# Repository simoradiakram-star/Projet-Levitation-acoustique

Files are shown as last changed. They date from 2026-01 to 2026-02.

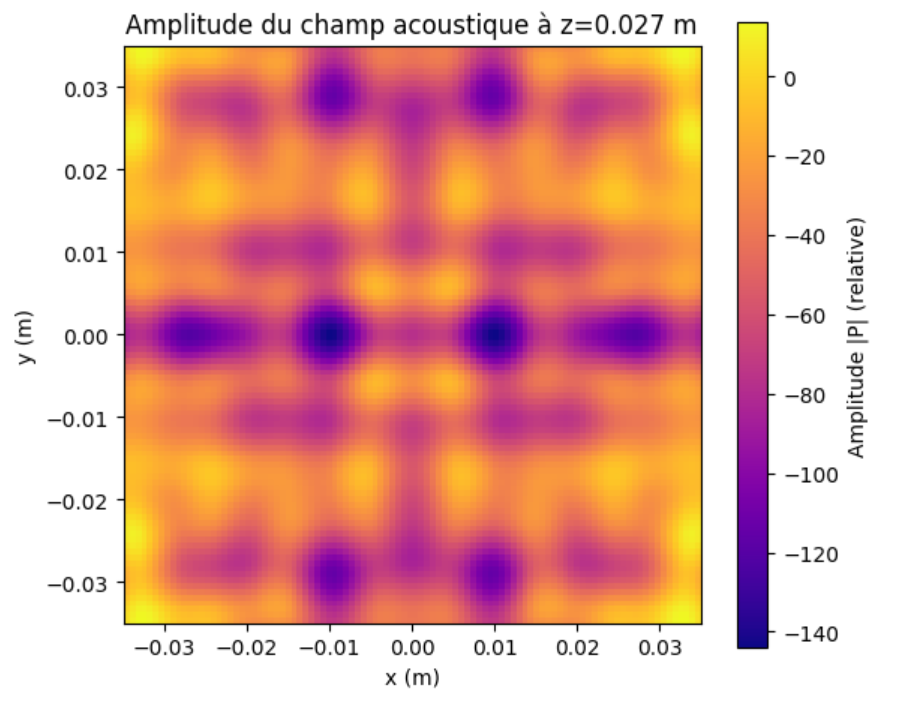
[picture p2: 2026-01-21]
Projet G1-G2/Lévitateur à deux plaques/Physique Théorique/Photos/optimizer 1 plaque (2).png

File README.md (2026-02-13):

# Système de Lévitation Acoustique

**Projet (G1 / G2) — Centrale Lille**

Développement d'un dispositif expérimental de manipulation sans contact par pinces acoustiques.

Photo_lévitation_1bille_bis

---

### À propos

Ce projet vise à concevoir et réaliser un système de lévitation acoustique à **faible coût**. L'objectif principal est de permettre la manipulation sans contact d'objets millimétriques (tels que des billes de polystyrène ou de petits insectes) dans l'air.

Ce travail s'inscrit dans la continuité des recherches du groupe **AIMAN-FILMS (IEMN)**, qui développe des technologies de pinces acoustiques pour des applications biomédicales (déplacement de cellules en milieu stérile). Notre prototype adapte ces concepts pour une application macroscopique dans l'air.

---

### 1. Objectifs

* **Conception :** Réaliser un prototype fonctionnel intégrant l'électronique et la structure mécanique.
* **Manipulation :** Réussir la lévitation stable d'objets millimétriques.
* **Démonstration :** Prouver la faisabilité d'applications potentielles (ex: manipulation d'échantillons fragiles).

### 2. Technologies et Compétences

Ce projet mobilise des compétences pluridisciplinaires :

* **Hardware / Électronique :** Soudure de cartes électroniques, pilotage de transducteurs.
* **Système embarqué :** Programmation sur Arduino.
* **Mécanique :** Modélisation et Impression 3D de la structure (support des transducteurs).
* **Physique :** Principes des ondes stationnaires et de la pression de radiation acoustique.

### 3. Partenaires et Encadrement

Ce projet est réalisé en partenariat avec le groupe **AIMAN-FILMS** de l'**IEMN** (Institut d'Électronique, de Microélectronique et de Nanotechnologie).

### 4. Contacts académiques

* **Olivier Bou Matar-Lacaze** (Centrale Lille / IEMN)
* **Abdelkrim Talbi** (Centrale Lille / IEMN)

---

Voici l'architecture globale du GitHub :

```
└── Projet-Levitation-acoustique
    ├── Lévitateur à deux plaques
    │   ├── Electronique
    │   │   ├── Circuits
    │   │   └── Composants
    │   ├── Informatique
    │   │   └── Communication 2 Arduino
    │   ├── Notices
    │   ├── Physique Théorique
    │   │   ├── Calcul des phases
    │   │   └── Photos
    │   └── Résultats  <-- (Vidéos de lévitation, rapports de tests)
    │
    ├── Lévitateur à une plaque
    │   ├── Electronique
    │   │   ├── Circuits
    │   │   └── Composants
    │   ├── Informatique
    │   │   ├── Code Arduino Mega
    │   │   │   ├── DriverMega
    │   │   │   └── NewDriverMega
    │   │   └── Codes Arduino Mega
    │   │       └── DriverMega
    │   ├── Notices
    │   ├── Physique théorique
    │   │   ├── Calcul des phases
    │   │   └── Photos
    │   └── Résultats  <-- (Vidéos, mesures de précision)
    │
    └── TinyLev
        └── Résultats  <-- (Démonstration du prototype compact)
```

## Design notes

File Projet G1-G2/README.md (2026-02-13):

# 📁 Nos Prototypes

Ce répertoire contient 3 dossiers permettant d'identifier clairement les 3 prototypes réalisés durant notre projet :

## 1. TinyLev (Prototype de Validation)

Le **TinyLev** est un lévitateur à ondes stationnaires.

* **Objectif** : Valider les principes fondamentaux de la lévitation acoustique et tester la chaîne d'amplification.
* **Caractéristique** : Utilise deux supports imprimés en 3D suivant une courbe prédéfinie pour focaliser les ultrasons au centre.

TinyLevenfonctionnement (1)

## 2. Lévitateur à Simple Plaque

Ce prototype marque le passage au contrôle dynamique via une matrice unique de **8x8 transducteurs**.

* **Capacités** : Permet de tester les algorithmes de calcul de phase (**Optimizer** et **Vortex**).
* **Limites** : Bien qu'il valide la création de pièges acoustiques, la force de lévitation reste limitée par l'absence d'une source d'opposition, rendant le piégeage d'objets lourds complexe.



## 3. Lévitateur à Double Plaques

Version la plus aboutie du projet, elle intègre deux matrices de transducteurs placées face à face.

* **Fonctionnement** : Génère des ondes stationnaires contrôlées par la synchronisation des deux plaques.
* **Avantages** :
* Augmentation considérable de la **force de piégeage**.
* **Stabilité supérieure** permettant la manipulation de liquides ou de plusieurs particules simultanément.

Photo_lévitation_1bille_bis

---

*Pour comprendre le déroulement de notre projet plus en détail et avoir une vue d'ensemble, vous pouvez vous référer à la documentation technique située à la racine de ce dossier.*

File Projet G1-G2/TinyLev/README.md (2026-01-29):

# Prototype 1 : TinyLev

Le **TinyLev** constitue la première étape concrète du projet. Il s'agit d'un lévitateur acoustique à ondes stationnaires dont la géométrie est fixe, permettant de valider les concepts physiques fondamentaux avant de passer à des systèmes dynamiques.

## Raison d'être

L'objectif principal de ce prototype était de :

* Confirmer la faisabilité de la lévitation d'objets millimétriques (billes de polystyrène) ;
* Se familiariser avec la manipulation des transducteurs ultrasonores à 40 kHz.

## Fonctionnalités

* **Focalisation géométrique** : La courbure de la structure imprimée en 3D assure la convergence des faisceaux ultrasonores vers un point focal central ;
* **Ondes stationnaires** : Création de nœuds de pression stables par interférence d'ondes permettant de piéger des particules à des positions fixes ;
* **Simplicité matérielle** : Pilotage via un Arduino Nano et une alimentation directe, sans besoin de calcul de phase complexe en temps réel.

## Limites

* **Position fixe** : Les pièges acoustiques sont statiques : il est impossible de déplacer la particule une fois lévitée ;
* **Absence de contrôle logiciel** : Le déphasage est induit par la position physique des transducteurs et non par le code.

## Évolution : Vers le Prototype 2 (Monoplaque)

Le succès du TinyLev a démontré que notre électronique de puissance était fiable. Cependant, pour répondre aux objectifs de manipulation dynamique, nous avons dû abandonner la géométrie fixe au profit d'une **matrice plane (8x8)** dont nous contrôlons chacun des transducteurs individuellement.

Le passage au prototype suivant permet d'introduire le **contrôle logiciel des phases**, offrant la flexibilité nécessaire pour déplacer les pièges acoustiques et manipuler les particules dans l'espace.

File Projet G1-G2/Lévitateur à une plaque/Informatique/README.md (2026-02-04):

# Pilotage Informatique - Lévitateur à une plaque

Ce dossier contient l'ensemble des ressources logicielles nécessaires au fonctionnement du prototype de lévitation acoustique à une plaque. 

## Structure du dossier

* **`Codes arduino mega/`** : Contient les scripts `.ino` pour l'Arduino Mega ainsi que les documentations d'explication de ces codes ;
* 
**`Passage_Phases_python_pin.ipynb`** : Notebook Python permettant de convertir les phases théoriques calculées en données binaires (octets) compréhensibles par l'Arduino.

---

## 🛠️ Instructions d'utilisation

### 1. Calcul des phases et conversion

Avant de téléverser le code sur l'Arduino, vous devez définir la position du piège acoustique :

1. Utilisez les scripts de calcul (Optimizer ou Vortex dans la partie physique théorique de la palque seule) pour obtenir les **phases réelles** (en radians) pour les 64 transducteurs ;
2. Ouvrez le notebook **`Passage_Phases_python_pin.ipynb`** ;
3. Renseignez vos phases réelles dans le tableau `Phi_64` ;
4. Exécutez le script pour générer le **bit buffer** (liste d'octets) ;
5. Copiez ces octets pour l'étape suivante.

### 2. Configuration de l'Arduino Mega

Le code de pilotage est une version optimisée du `DriverMega` original, nommée `NewDriverMega`.

1. Ouvrez le sketch dans le dossier `Codes arduino mega`.
2. Remplacez les octets de la variable `patterns` (ligne 24 environ) par ceux générés par le notebook.

3. **Note sur les motifs (patterns)** : Le code est configuré pour 2 motifs.
* Pour un piège statique : copiez deux fois le même set de phases.
* Pour un déplacement : renseignez deux sets de phases proches l'un de l'autre.

4. Sélectionnez la carte **Arduino Mega** dans l'IDE et téléversez le programme.

---

## ⚠️ Précautions

* 
**Alimentation** : Ne jamais dépasser **29V** sur la carte d'amplification.

* 
**Connectique** : Vérifiez la continuité des câbles en nappe, car des fils trop fins peuvent causer des pertes de signal.

* 
**Synchronisation** : Si le signal n'est pas stable à l'oscilloscope, ajustez ou supprimez le nombre de `nop` dans la fonction `WAIT()`.

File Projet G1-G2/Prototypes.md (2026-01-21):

Nos Prototypes
Lévitateur à Simple Plaque (Phase 2) Ce prototype initial utilise une matrice unique de 8x8 transducteurs. Il a permis de valider les algorithmes de calcul de phase (Optimizer et Vortex) pour créer des pièges acoustiques , bien que la force de lévitation reste limitée dans cette configuration.

Lévitateur à Double Plaque (Phase 3) Cette version évoluée intègre deux matrices de transducteurs placées face à face. Grâce à la génération d'ondes stationnaires, ce système augmente considérablement la force de piégeage , offrant une stabilité supérieure nécessaire pour faire léviter des liquides ou manipuler plusieurs particules simultanément.

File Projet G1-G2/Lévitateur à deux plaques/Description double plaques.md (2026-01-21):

# Prototype 2 : Lévitateur à Double Plaque

Ce prototype constitue la phase 3 du projet. Il utilise deux matrices en vis-à-vis pour créer des ondes stationnaires et augmenter la force de lévitation.

## Organisation des dossiers

### 📁 Electronique
Ce dossier détaille l'adaptation matérielle pour deux plaques :
* **Schémas** 
* **Câblage** 

### 📁 Informatique
Ce dossier contient les outils pour la gestion synchronisée :
* **Codes Arduino** 
* **Génération de phases** 

### 📁 Physique théorique
* **Calcul des phases** 
* **Comparaisons** 

---
## Objectif
Obtenir une lévitation très stable permettant de manipuler des liquides ou plusieurs objets à la fois.

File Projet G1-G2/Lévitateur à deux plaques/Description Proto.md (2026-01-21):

# Prototype 2 : Lévitateur à Double Plaque

Ce prototype constitue la phase 3 du projet. Il utilise deux matrices en vis-à-vis pour créer des ondes stationnaires et augmenter la force de lévitation.

## Organisation des dossiers

### 📁 Electronique
Ce dossier détaille l'adaptation matérielle pour deux plaques :
* **Schémas** : Plans pour les deux matrices (haute et basse) et leurs drivers améliorés.
* **Câblage** : Schéma de connexion spécifique pour relier les deux systèmes ensemble.

### 📁 Informatique
Ce dossier contient les outils pour la gestion synchronisée :
* **Codes Arduino (Master/Slave)** : Deux programmes distincts sont fournis. L'un pour la plaque du bas (Maître), l'autre pour celle du haut (Esclave).
* **Génération de phases** : Scripts adaptés pour calculer les pièges sur l'ensemble des 128 transducteurs simultanément.

### 📁 Physique théorique
* **Comparaison** : Documents montrant les gains de stabilité obtenus grâce aux ondes stationnaires par rapport au premier prototype.

---
## Objectif
Obtenir une lévitation très stable permettant de manipuler des liquides ou plusieurs objets à la fois.

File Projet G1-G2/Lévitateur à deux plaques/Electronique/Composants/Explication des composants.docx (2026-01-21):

Explication des composants

TC 44 27 :

Le TC4427 est un driver de MOSFET conçu pour piloter des transistors MOSFET à grille à haute capacité. Il est couramment utilisé pour amplifier des signaux de commande provenant de microcontrôleurs ou d'autres circuits logiques afin de piloter des charges plus importantes.

### Fonctionnement du TC4427

- Double driver : Il contient deux drivers indépendants capables de fournir un courant de sortie élevé (jusqu'à 1,5 A en crête).
- Commande de MOSFET : Il convertit un signal logique de faible puissance en un signal de puissance plus élevé, permettant d’activer efficacement des MOSFETs.
- Sortie push-pull : Chaque canal possède une sortie de type push-pull (complètement active en montée et en descente), ce qui réduit le temps de commutation et limite les pertes de puissance.

### Caractéristiques principales

- Tension d’alimentation (Vdd) : 4,5V à 18V
- Courant de sortie : 1,5 A (max)
- Temps de commutation rapide :
  - Temps de montée : ~25 ns
  - Temps de descente : ~25 ns
- Entrée compatible logique TTL et CMOS
- Protection contre les inversions de tension d’alimentation

### Utilisation du TC4427

Le TC4427 est utilisé dans plusieurs applications, notamment :

1. Commande de MOSFETs : Pour piloter des transistors MOSFET dans des circuits de commutation ou d’amplification de puissance.
2. Alimentation à découpage (SMPS) : Pour améliorer les performances de commutation des transistors dans des convertisseurs DC-DC.
3. Commande de moteurs : Dans les circuits de contrôle de moteurs à courant continu (DC).
4. Commande de relais et solénoïdes : Pour activer des charges inductives plus importantes.
5. Circuits RF et haute fréquence : Grâce à ses temps de commutation rapides.

### Exemple de schéma d'utilisation

Si l'on souhaite piloter un MOSFET de puissance (ex : IRF540) avec un signal logique 5V issu d'un microcontrôleur (ex : Arduino), voici un schéma de base :

markdown

CopierModifier

+12V

│

│

┌┴┐

Drain │MOSFET│

└┬┘

│

├───(Charge)

│

│

GND

Le TC4427 est connecté ainsi :

- Vdd = 12V (ou 5V si besoin)
- Entrée IN = Signal du microcontrôleur (0V/5V)
- Sortie OUT = Connectée à la grille du MOSFET
- GND = Masse commune avec le circuit

Ce montage permet au microcontrôleur de commander efficacement un MOSFET de puissance sans souffrir des limitations de courant de ses broches de sortie.

### Avantages du TC4427

✅ Peut fonctionner sous une large plage de tensions (4,5V à 18V)
✅ Capable de fournir un fort courant de sortie (jusqu'à 1,5 A)
✅ Temps de commutation rapide, idéal pour des applications haute fréquence
✅ Conception robuste avec protection contre les inversions de tension

En résumé, le TC4427 est un driver MOSFET polyvalent qui améliore la commutation rapide et efficace des transistors MOSFET dans divers circuits de puissance.

### Utilité des broches :

1. IN A (Broche 1) : Entrée du premier driver (signal logique 0V ou 5V).
2. IN B (Broche 2) : Entrée du second driver (signal logique 0V ou 5V).
3. GND (Broche 3, 4, 5) : Masse du circuit (doit être connectée à la masse du système).
4. OUT B (Broche 6) : Sortie du second driver (connectée à la grille du MOSFET ou autre charge).
5. OUT A (Broche 7) : Sortie du premier driver (connectée à la grille du MOSFET ou autre charge).
6. VDD (Broche 8) : Alimentation du circuit (4.5V à 18V, selon l'application).

pour notre situation avec des transducteurs piézoélectriques :

Entrée (IN A/B) : Signal PWM venant d’un microcontrôleur (ex: Arduino).

Sortie (OUT A/B) : Connectée directement au transducteur piézoélectrique.

VDD : Tension adaptée au transducteur (ex: 12V pour une puissance plus élevée).

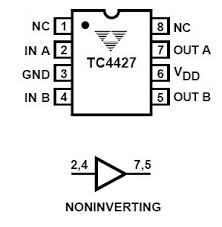
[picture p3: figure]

Les broches NC (Not Connected) sur le TC4427 (broches 1 et 8 dans ton schéma) ne sont pas connectées en interne au circuit du composant.

### Pourquoi y a-t-il des broches NC ?

1. Stabilité mécanique : Elles aident à maintenir la symétrie et la robustesse du boîtier.
2. Compatibilité avec d'autres versions : Certains boîtiers de circuits intégrés ont des broches NC pour faciliter le remplacement par des composants similaires.
3. Future évolution : Ces broches pourraient être utilisées dans des versions futures du circuit intégré.

En résumé, ces broches n'ont pas d'effet sur le fonctionnement du TC4427 et peuvent être laissées non connectées dans un circuit.

Le TC4427 contient deux drivers indépendants, ce qui permet de piloter deux MOSFETs ou charges différentes avec un seul composant. Les sorties sont push-pull, ce qui signifie qu'elles peuvent à la fois fournir du courant (source) et en absorber (sink), facilitant la commutation rapide des transistors.

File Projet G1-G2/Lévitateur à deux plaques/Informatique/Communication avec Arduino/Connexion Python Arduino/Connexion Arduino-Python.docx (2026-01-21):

L’IA Claude m’a écrit ça !

import numpy as np

import math as m

from scipy.optimize import minimize

import serial

import time

from threading import Thread, Event

import struct

# Constantes physiques

k = 2 * m.pi * 40000 / 343

R_p = 0.004

c_p = 40

rho_p = 2400

c_0 = 343

rho_0 = 1.293

eps = 1e-5

# Grille des transducteurs

a = 0.01

n = 8

X_j, Y_j = [], []

l = np.linspace(-(n // 2 - 0.5) * a, (n // 2 - 0.5) * a, n)

for y in l:

for x in l:

X_j.append(x)

Y_j.append(y)

Z_j = [0] * len(X_j)

##fonctions utiles

def d(xj, yj, zj, xf, yf, zf):

return m.sqrt((xj - xf)**2 + (yj - yf)**2 + (zj - zf)**2)

def D_F(xj, yj, zj, x, y, z):

theta = m.atan(m.sqrt((x - xj)**2 + (y - yj)**2) / (z - zj))

if (theta == 0):

return 1

else:

return m.sin(k * R_p * m.sin(theta)) / (k * R_p * m.sin(theta))

def K1(R, c_p, rho_p):

V = 4 * m.pi / 3 * R**3

a0 = 1 / (c_0**2 * rho_0)

ap = 1 / (c_p**2 * rho_p)

return V / 4 * (a0 - ap)

def K2(R, omega, rho_p):

V = 4 * m.pi / 3 * R**3

return 3 * V / 4 * ((rho_0 - rho_p) / (omega**2 * rho_0 * (rho_0 + 2 * rho_p)))

def f(xj, yj, zj, x, y, z, phi):

dj = d(xj, yj, zj, x, y, z)

df = D_F(xj, yj, zj, x, y, z)

return df / dj * np.exp(1j * (k*dj+phi))

##calcul du potentiel de gorkov

def p_tot(x, y, z, phi_vals):

ptot = 0

for i in range(len(phi_vals)):

ptot += f(X_j[i], Y_j[i], Z_j[i], x, y, z, phi_vals[i])

return ptot

def grad_p(x, y, z, phi_vals):

dp_dx = (p_tot(x+eps, y, z, phi_vals) - p_tot(x, y, z, phi_vals)) / eps

dp_dy = (p_tot(x, y+eps, z, phi_vals) - p_tot(x, y, z, phi_vals)) / eps

dp_dz = (p_tot(x, y, z+eps, phi_vals) - p_tot(x, y, z, phi_vals)) / eps

return [dp_dx, dp_dy, dp_dz]

def gorkov_potential(x, y, z, phi_vals):

p_complex = p_tot(x, y, z, phi_vals)

gradp = grad_p(x, y, z, phi_vals)

omega = 2 * np.pi * 40000

k1 = K1(R_p, c_p, rho_p)

k2 = K2(R_p, omega, rho_p)

abs_p2 = abs(p_complex)**2

abs_gradp2 = 0

for x in gradp:

abs_gradp2 += abs(x)**2

U = k1*abs_p2 - k2*abs_gradp2

return U

def lap_U(x, y, z, phi_vals):

dU_dxx = (gorkov_potential(x + eps, y, z, phi_vals) - gorkov_potential(x - eps, y, z, phi_vals)) / (eps**2)

dU_dyy = (gorkov_potential(x, y + eps, z, phi_vals) - gorkov_potential(x, y - eps, z, phi_vals)) / (eps**2)

dU_dzz = (gorkov_potential(x, y, z + eps, phi_vals) - gorkov_potential(x, y, z - eps, phi_vals)) / (eps**2)

return dU_dxx + dU_dyy + dU_dzz

##optimisation de la force :

def F_opt(xf, yf, zf, phi_vals):

ptot = p_tot(xf, yf, zf, phi_vals)

lapU = lap_U(xf, yf, zf, phi_vals)

return abs(ptot) - lapU

def optimizer(xf, yf, zf):

def objective(phi_vals):

return F_opt(xf, yf, zf, phi_vals)

phi0 = np.zeros(n**2)

result = minimize(objective, phi0, method='L-BFGS-B', bounds=[(0, 2*np.pi)] * (n**2))

print("Phases optimales trouvées :")

print(result.x)

return result.x

class GorkovArduinoController:

def __init__(self, port='COM3', baudrate=115200):

"""

Contrôleur combinant calcul de Gorkov et communication Arduino

"""

self.port = port

self.baudrate = baudrate

self.serial_conn = None

# Constantes du protocole Arduino

self.N_PATTERNS = 32

self.N_PORTS = 10 # Limité à 10 dans l'Arduino (vous avez 64 transducteurs)

self.N_DIVS = 10 # Divisions temporelles par période

# Commandes du protocole

self.COMMAND_SWITCH = 0b00000000

self.COMMAND_DURATION = 0b00110000

self.MASK_DURATION = 0b00111111

self.COMMAND_COMMITDURATIONS = 0b00010000

# ID de l'Arduino

self.ARDUINO_ID = 1

# Configuration des transducteurs

self.transducer_positions = list(zip(X_j, Y_j, Z_j))

self.n_transducers = len(self.transducer_positions)

# Thread control

self.stop_event = Event()

self.update_thread = None

print(f"Contrôleur initialisé avec {self.n_transducers} transducteurs")

def connect(self):

"""Connexion à l'Arduino"""

try:

self.serial_conn = serial.Serial(self.port, self.baudrate, timeout=1)

time.sleep(2) # Attendre la réinitialisation de l'Arduino

print(f"Connecté à l'Arduino sur {self.port}")

return True

except serial.SerialException as e:

print(f"Erreur de connexion: {e}")

return False

def disconnect(self):

"""Déconnexion de l'Arduino"""

if self.serial_conn and self.serial_conn.is_open:

self.serial_conn.close()

print("Déconnecté de l'Arduino")

def calculate_phases_for_point(self, xf, yf, zf):

"""

Calcule les phases optimales pour un point focal donné

"""

print(f"Calcul des phases pour le point focal ({xf:.3f}, {yf:.3f}, {zf:.3f})")

# Utiliser votre optimiseur Gorkov

optimal_phases = optimizer(xf, yf, zf)

return optimal_phases

def phases_to_arduino_format(self, phases, time_division=0):

"""

Convertit les phases en format compatible Arduino

Args:

phases: Array des phases (0 à 2π)

time_division: Division temporelle (0-9)

Returns:

Array des bytes à envoyer à l'Arduino

"""

# Ajouter l'offset temporel

phase_offset = (time_division / self.N_DIVS) * 2 * np.pi

adjusted_phases = (phases + phase_offset) % (2 * np.pi)

arduino_data = []

# L'Arduino ne peut contrôler que 10 transducteurs

# On prend les premiers ou on fait une sélection intelligente

selected_phases = adjusted_phases[:self.N_PORTS] if len(adjusted_phases) >= self.N_PORTS else adjusted_phases

for i in range(self.N_PORTS):

if i < len(selected_phases):

# Convertir la phase (0-2π) en valeur 4-bit (0-15)

phase_4bit = int((selected_phases[i] / (2 * np.pi)) * 15) & 0x0F

# Amplitude fixe maximale (4 bits hauts)

amplitude_4bit = 0xF # Amplitude maximale

# Combiner dans un byte

data_byte = (amplitude_4bit << 4) | phase_4bit

else:

data_byte = 0x00 # Transducteur éteint

arduino_data.append(data_byte)

return np.array(arduino_data, dtype=np.uint8)

def send_switch_command(self):

"""Envoie la commande SWITCH"""

if self.serial_conn:

self.serial_conn.write(bytes([self.COMMAND_SWITCH]))

response = self.serial_conn.read(1)

return len(response) > 0 and response[0] == self.COMMAND_SWITCH

return False

def send_pattern_to_arduino(self, phases, pattern_idx=0):

"""

Envoie un pattern de phases à l'Arduino

Args:

phases: Phases calculées par l'optimiseur Gorkov

pattern_idx: Index du pattern (0-31)

"""

if not self.serial_conn:

print("Erreur: Pas de connexion série")

return False

print(f"Envoi du pattern {pattern_idx}...")

# Générer les données pour chaque division temporelle

for div_idx in range(self.N_DIVS):

arduino_data = self.phases_to_arduino_format(phases, div_idx)

# Envoyer chaque transducteur

for port_idx in range(self.N_PORTS):

# Préparer le byte selon le protocole Arduino

data_byte = arduino_data[port_idx]

# Ajouter l'ID Arduino dans les 4 bits de poids faible

command_byte = (data_byte & 0xF0) | self.ARDUINO_ID

self.serial_conn.write(bytes([command_byte]))

time.sleep(0.001) # Petite pause

return True

def send_durations(self, durations=None):

"""Envoie les durées des patterns"""

if durations is None:

durations = np.ones(self.N_PATTERNS, dtype=np.uint8)

if not self.serial_conn:

return False

print("Envoi des durées...")

# Envoyer les durées (protocole Arduino : 4 durées par message)

for i in range(0, self.N_PATTERNS, 4):

for j in range(4):

if i + j < self.N_PATTERNS:

duration = durations[i + j] & 0b11

command_byte = self.COMMAND_DURATION | (duration << (6 - j * 2))

self.serial_conn.write(bytes([command_byte]))

time.sleep(0.001)

# Commit les durées

self.serial_conn.write(bytes([self.COMMAND_COMMITDURATIONS]))

response = self.serial_conn.read(1)

success = len(response) > 0 and response[0] == self.COMMAND_COMMITDURATIONS

if success:

print("Durées envoyées et commitées")

return success

def levitate_particle_at_point(self, xf, yf, zf):

"""

Calcule et envoie les phases pour léviter une particule à un point donné

Args:

xf, yf, zf: Coordonnées du point focal (en mètres)

"""

try:

# 1. Calculer les phases optimales avec Gorkov

print(f"Calcul des phases pour le point ({xf}, {yf}, {zf})...")

optimal_phases = self.calculate_phases_for_point(xf, yf, zf)

# 2. Envoyer le switch command

if not self.send_switch_command():

print("Erreur lors du switch command")

return False

# 3. Envoyer les données de pattern

if not self.send_pattern_to_arduino(optimal_phases, pattern_idx=0):

print("Erreur lors de l'envoi du pattern")

return False

# 4. Envoyer les durées

if not self.send_durations():

print("Erreur lors de l'envoi des durées")

return False

print(f"✓ Particule configurée pour lévitation au point ({xf:.3f}, {yf:.3f}, {zf:.3f})")

return True

except Exception as e:

print(f"Erreur lors de la configuration: {e}")

return False

def real_time_tracking(self, trajectory_function, update_rate=5):

"""

Suivi temps réel d'une trajectoire

Args:

trajectory_function: Fonction qui retourne (x, y, z) en fonction du temps

update_rate: Fréquence de mise à jour (Hz)

"""

def tracking_loop():

start_time = time.time()

while not self.stop_event.is_set():

try:

current_time = time.time() - start_time

# Obtenir la position cible

xf, yf, zf = trajectory_function(current_time)

# Calculer et envoyer les nouvelles phases

self.levitate_particle_at_point(xf, yf, zf)

# Attendre avant la prochaine mise à jour

time.sleep(1.0 / update_rate)

except Exception as e:

print(f"Erreur dans la boucle de tracking: {e}")

time.sleep(0.1)

# Démarrer le thread de tracking

self.update_thread = Thread(target=tracking_loop)

self.update_thread.daemon = True

self.update_thread.start()

print(f"Tracking temps réel démarré à {update_rate} Hz")

def stop_tracking(self):

"""Arrête le tracking temps réel"""

self.stop_event.set()

if self.update_thread:

self.update_thread.join()

print("Tracking temps réel arrêté")

# Fonctions d'exemple pour les trajectoires

def static_point_trajectory(t):

"""Point fixe au centre"""

return (0.0, 0.0, 0.02) # 2cm au-dessus du centre

def circular_trajectory(t):

"""Trajectoire circulaire"""

radius = 0.01 # 1cm de rayon

omega = 2 * np.pi * 0.5 # 0.5 Hz

x = radius * np.cos(omega * t)

y = radius * np.sin(omega * t)

z = 0.02 # 2cm de hauteur

return (x, y, z)

def figure_eight_trajectory(t):

"""Trajectoire en forme de 8"""

omega = 2 * np.pi * 0.3 # 0.3 Hz

x = 0.01 * np.sin(omega * t)

y = 0.005 * np.sin(2 * omega * t)

z = 0.02

return (x, y, z)

# Exemple d'utilisation

def main_example():

"""Exemple principal d'utilisation"""

# Créer le contrôleur

controller = GorkovArduinoController(port='COM3') # Ajuster le port

try:

# Connexion

if not controller.connect():

print("Impossible de se connecter à l'Arduino")

return

print("=== Test de lévitation à un point fixe ===")

# Test 1: Point fixe

success = controller.levitate_particle_at_point(0.0, 0.0, 0.02)

if success:

print("Configuration réussie pour point fixe")

time.sleep(5)

print("\n=== Test de trajectoire circulaire ===")

# Test 2: Trajectoire circulaire en temps réel

controller.real_time_tracking(circular_trajectory, update_rate=2)

# Laisser tourner pendant 20 secondes

print("Trajectoire circulaire en cours... (20s)")

time.sleep(20)

print("\n=== Test de trajectoire en 8 ===")

# Test 3: Trajectoire en forme de 8

controller.stop_tracking()

controller.real_time_tracking(figure_eight_trajectory, update_rate=3)

print("Trajectoire en 8 en cours... (20s)")

time.sleep(20)

except KeyboardInterrupt:

print("\nInterruption par l'utilisateur")

finally:

controller.stop_tracking()

controller.disconnect()

print("Programme terminé")

if __name__ == "__main__":

main_example()

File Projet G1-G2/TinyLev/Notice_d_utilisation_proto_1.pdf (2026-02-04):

# NOTICE D’UTILISATION DU TINYLEV

## Guide de mise en route du TinyLev

3 février 2026

## Sommaire

1 Étape 1 : Vérification du matériel | 2
2 Étape 2 : Alimentation électrique | 2
3 Étape 3 : Connexion PC | 3
4 Étape 4 : Récupération du code | 3
5 Étape 5 : Configuration du logiciel | 3
6 Étape 6 : Mise en route | 3
7 Étape 7 : Placer la bille | 3

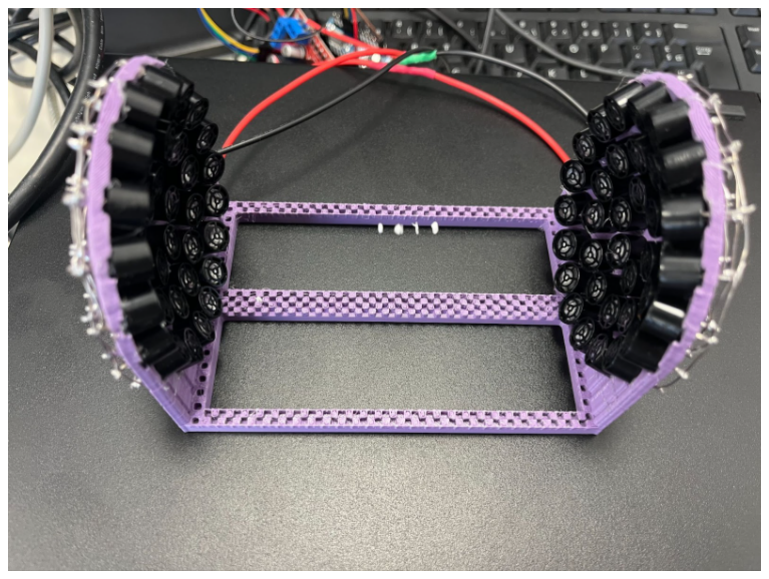
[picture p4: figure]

Figure 1 – TinyLev opérationnel

## 1 Étape 1 : Vérification du matériel

Vérifier que tous les composants sont présents sur le système et que les branchements sont faits conformément au schéma ci-dessous :

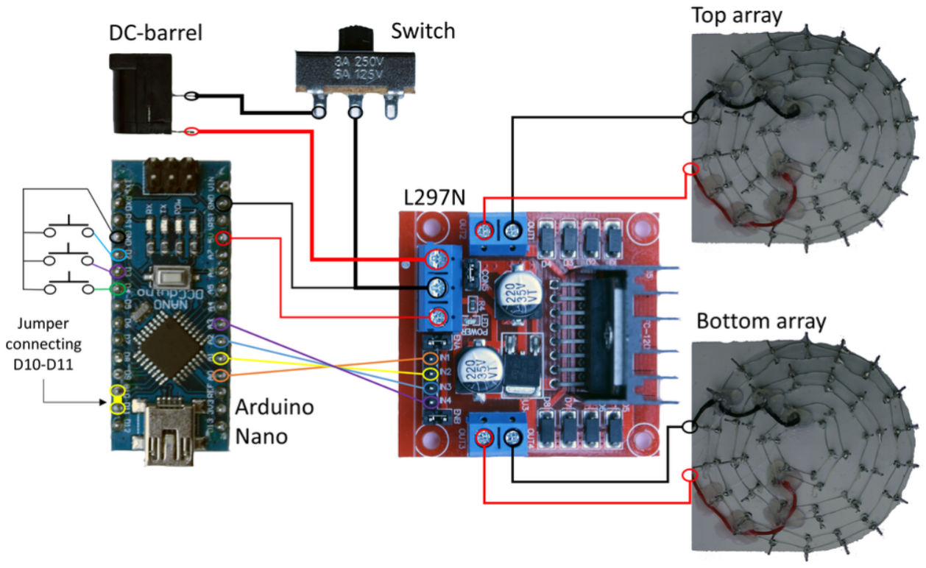
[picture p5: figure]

Figure 2 – Schéma de branchement du TinyLev - Source : Instructables (https://www.instructables.com/Acoustic-Levitator/)

- Vérification cruciale : Vérifier en particulier les fils qui connectent l’Arduino Nano au L297N ;
- Jumper : Vérifier qu’un fil connecte le port 10 au port 11 de l’Arduino (fil mâlemâle).

## 2 Étape 2 : Alimentation électrique

Brancher le système sur secteur avec le chargeur, sur le DC-barrel.

Attention : Un des chargeurs de la boîte ne fonctionne plus. Vérifiez que des lumières s’allument sur les cartes lors du branchement.

## 3 Étape 3 : Connexion PC

Branchez en USB la carte Arduino avec un PC muni du logiciel Arduino IDE.

## 4 Étape 4 : Récupération du code

1. Rendez-vous sur la page : Acoustic Levitator: 27 Steps - Instructables; (https://www.instructables.com/Acoustic-Levitator/)
2. Ouvrez le fichier Arduino fourni à l’étape 13 du tutoriel.

## 5 Étape 5 : Configuration du logiciel

Dans le menu Outils de l’Arduino IDE :
- Type de carte : Choisissez "Arduino Nano" ;
- Processeur : Choisissez "ATmega328P (Old Bootloader)" ;
- Port : Sélectionnez le port détecté (ex : COM3).

## 6 Étape 6 : Mise en route

1. Cliquez sur le bouton Vérifier ;
2. Cliquez sur le bouton Téléverser.

## 7 Étape 7 : Placer la bille

Le prototype 1 est maintenant en fonctionnement. Approchez une petite particule (petit morceau de polystyrène), elle devrait léviter.

Note technique : La distance minimale entre deux particules est de 4,25 mm.

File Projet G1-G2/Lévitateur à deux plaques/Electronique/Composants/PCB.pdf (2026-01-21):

## HQDFM Design for Manufacture(DFM) Report

### File name: 0000A328399_1

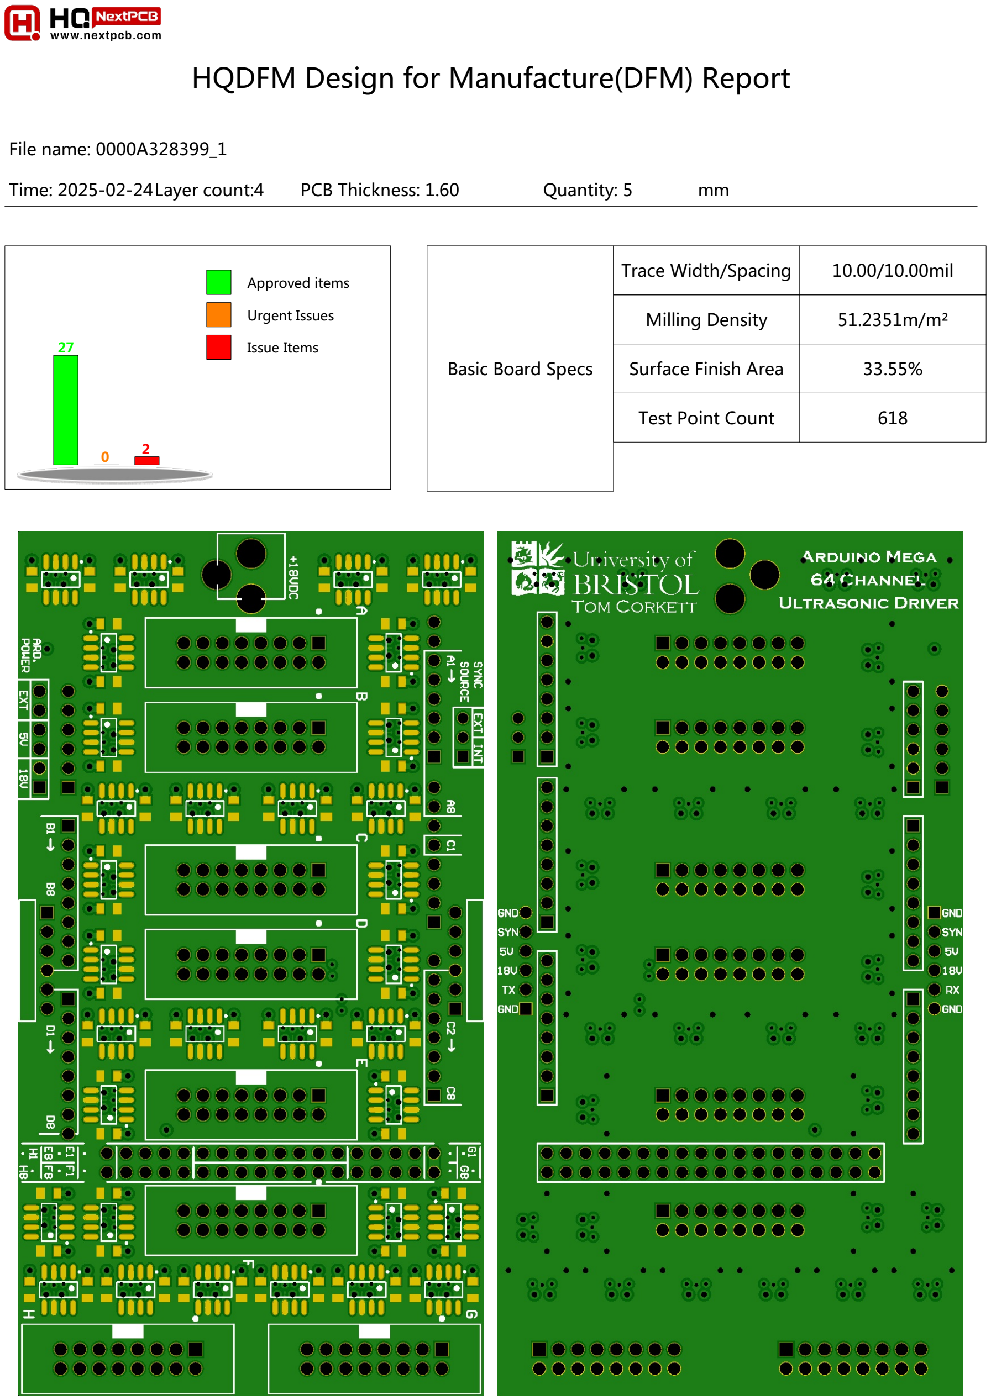
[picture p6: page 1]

Time: 2025-02-24Layer count:4 | PCB Thickness: 1.60 | Quantity: 5
mm

Approved items

Urgent Issues

### 27 Issue Items

0

2

Basic Board Specs

Trace Width/Spacing | 10.00/10.00mil
Milling Density | 51.2351m/m²
Surface Finish Area | 33.55%
Test Point Count | 618

Type | Category | No. of Checks | Result
| Open/Shorts (IPC) | 1 | Fail
| Signal Integrity | 4 | Pass
| Smallest Trace Width | 1 | Pass 3
| Smallest Trace Spacing | 3 | Pass 131
| SMD Pad Spacing | 1 | Pass
| Pad Size | 3 | Pass 4
| Hatched Copper Pour | 2 | Pass
| Annular Ring Size | 2 | Pass 4
| Drill to Copper | 5 | Pass 1023
| Copper-to-Board Edge | 2 | Pass 1 , Fail 8
| Holes on SMD Pads | 4 | Pass
PCB Drilling Analysis | Drill Diameter | 8 | Pass 24
| Drill Hole Density | 1 | Pass
| Drill Diameter | 8 | Pass 24
| Drill Spacing | 4 | Pass 96
| Drill to Board Edge | 4 | Pass
| Drill Hole Density | 1 | Pass
| Special Drill Holes | 2 | Pass
| Drill Hole Errors | 3 | Pass
PCB Solder Mask Analysis | Solder Mask Dam | 2 | Pass
| Missing SMask Opening | 1 | Pass
| Solder Paste Area | 1 | Pass
PCB Silk Analysis | Silkscreen Spacing | 1 | Pass
PCBA Fiducial Analysis | Fiducial Count | 1 | Fail

PCB Trace Analysis

ID

C

h

eck | Limits | V

### alu

e | Issu
e | Im
a

g

e

P

### ositio

n

## Qty Le

v

el 1 | Copper-to- Board Edge_Cop per-to- Board Edge | 8,15,20 | 0.00 mm | For most factories, the copper-to-board edge clearance requirement is 0.2 mm. Failure to meet the factory's requirements could increase the risk of exposed copper on the edge of the boards or damaged traces/pads, which decrease manufacturing efficiency and yield, and affect the reliability of the boards. Copper-to-board edge spacing of 0.00mil was detected in your design. It is recommended to increase the spacing to at least 0.25 mm for edge routing and 0.4 mm for v- cuts (v-cut spacing may depends on board thickness). | 0.00,114.05 | 4 | Risk

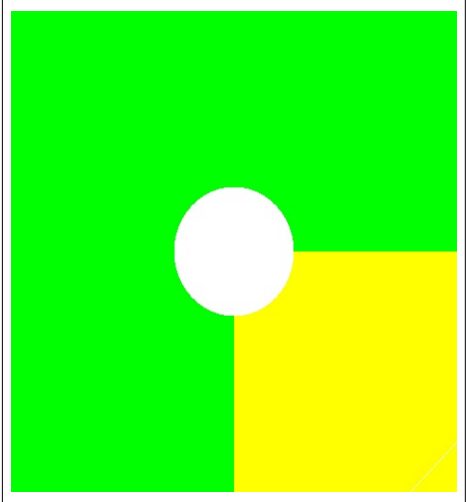
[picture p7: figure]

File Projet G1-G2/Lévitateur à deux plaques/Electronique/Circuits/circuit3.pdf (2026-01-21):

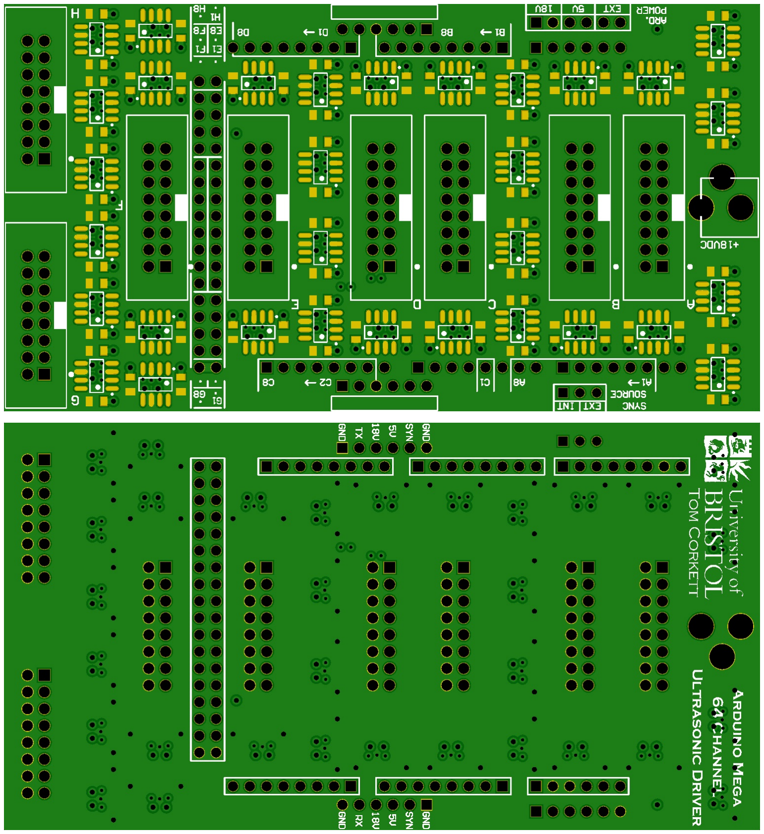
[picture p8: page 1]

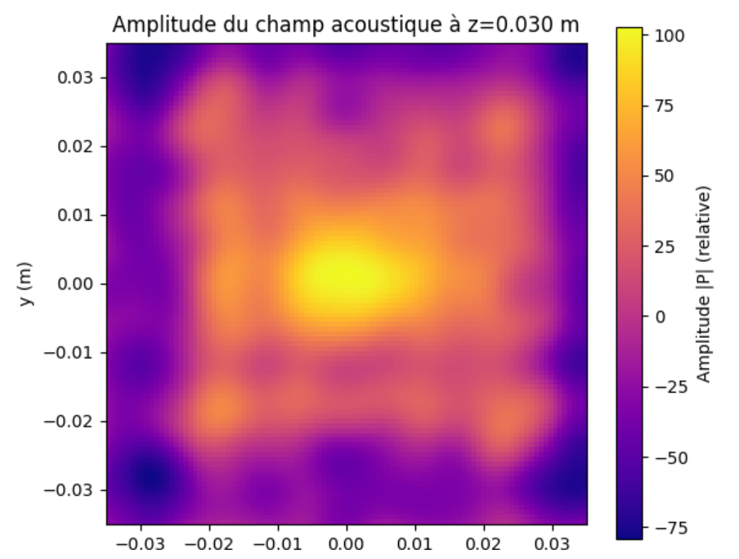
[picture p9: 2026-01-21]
Projet G1-G2/Lévitateur à deux plaques/Physique Théorique/Photos/vortex 2 plaque.png

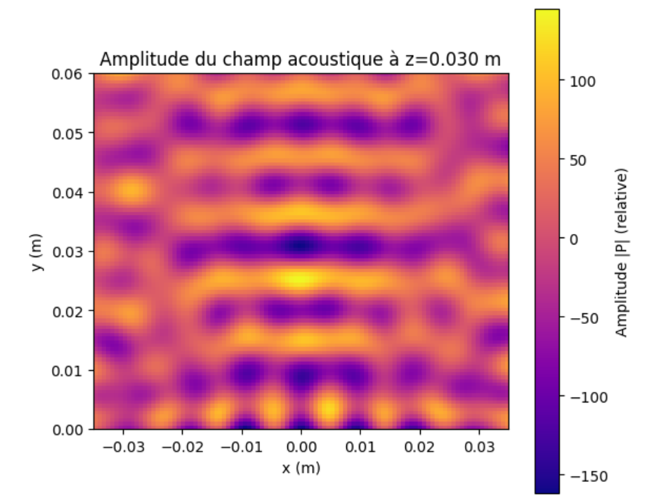
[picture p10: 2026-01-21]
Projet G1-G2/Lévitateur à deux plaques/Physique Théorique/Photos/vortex 2 plaque (3).png

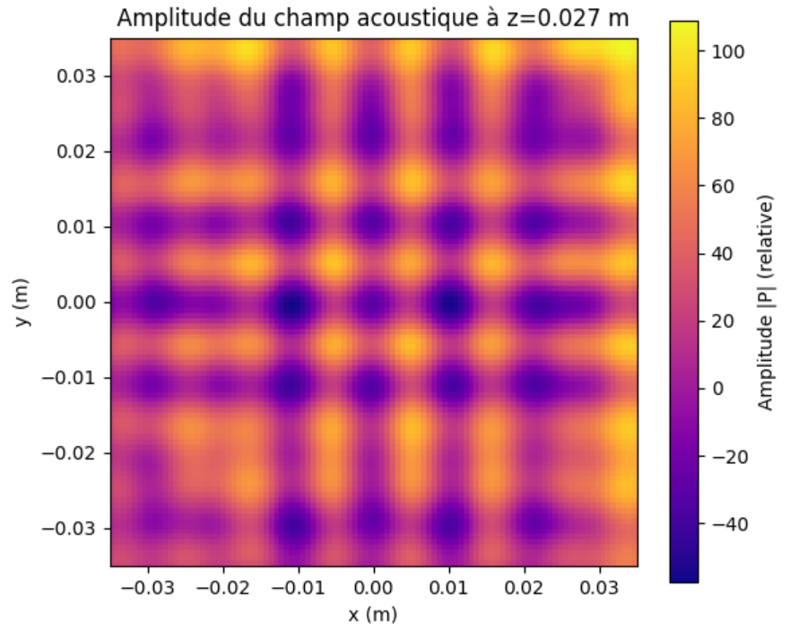
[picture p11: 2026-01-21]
Projet G1-G2/Lévitateur à deux plaques/Physique Théorique/Photos/optimizer 2 plaque (2).png

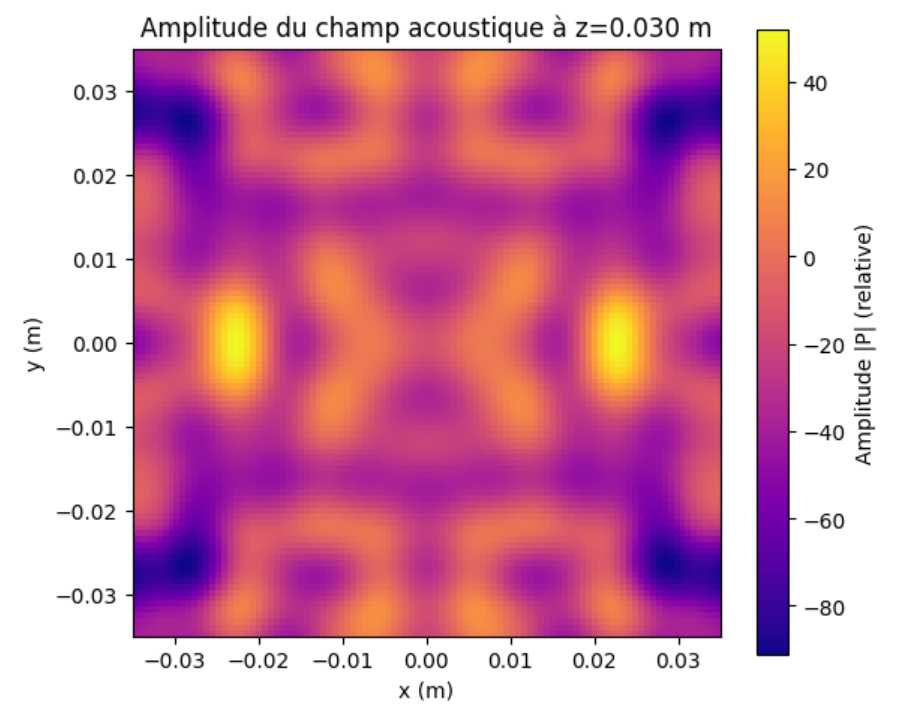
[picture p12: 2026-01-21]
Projet G1-G2/Lévitateur à deux plaques/Physique Théorique/Photos/optimizer 1 plaque.png

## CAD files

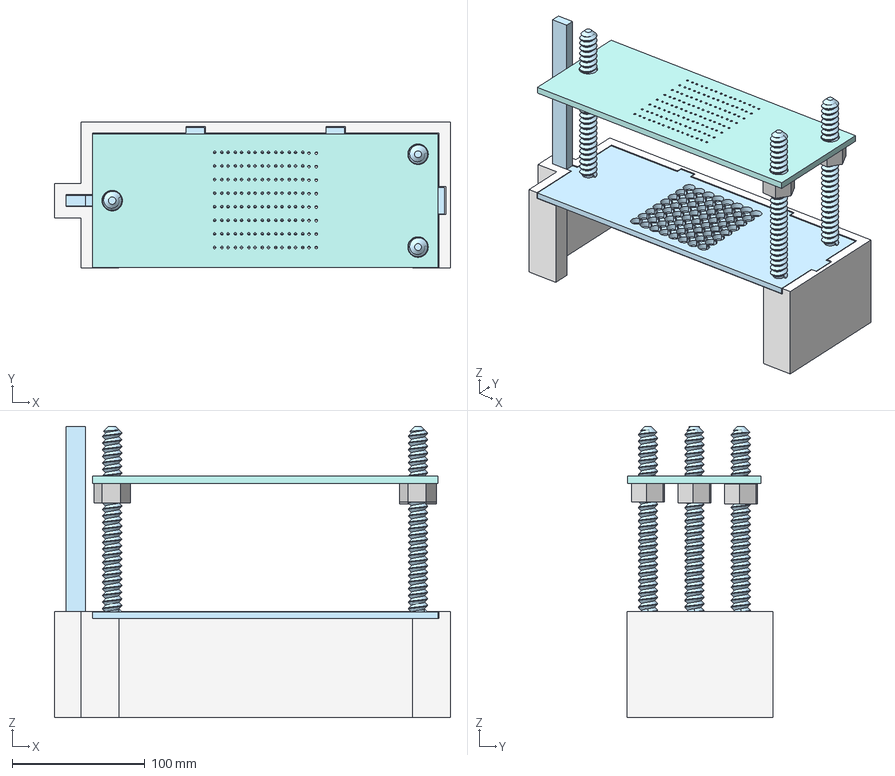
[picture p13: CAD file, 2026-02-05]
Projet G1-G2/Lévitateur à deux plaques/Conception Assistée par Ordinateur/Montage Prototype 3.step
298.7 x 110.2 x 219.5 mm
�crou n�1 x 3
Plaque basse x 2

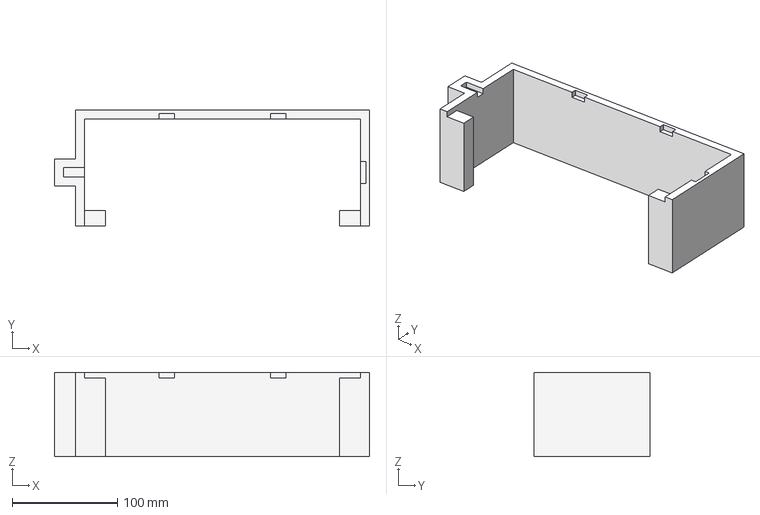
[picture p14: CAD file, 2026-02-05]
Projet G1-G2/Lévitateur à deux plaques/Support Prototype 3.step
298.7 x 110.2 x 80.0 mm

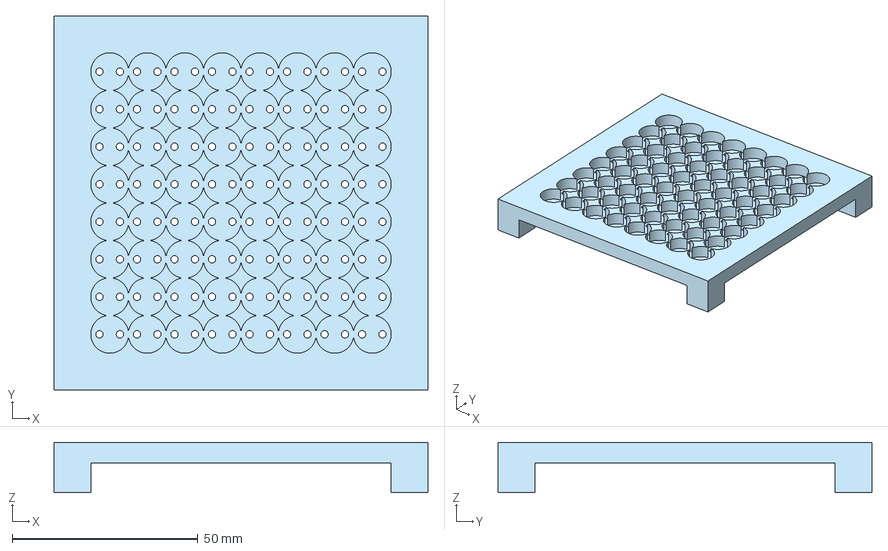
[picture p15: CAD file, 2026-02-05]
Projet G1-G2/Lévitateur à une plaque/Conception Assistée par Ordinateur/Plaque Prototoype 2.step
100.7 x 100.7 x 13.5 mm

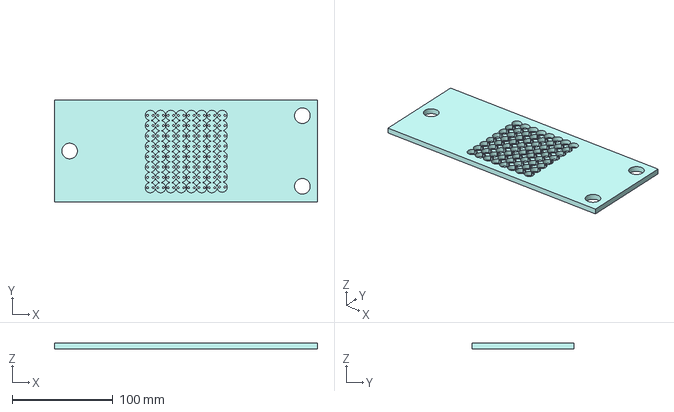
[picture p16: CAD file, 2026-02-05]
Projet G1-G2/Lévitateur à deux plaques/Conception Assistée par Ordinateur/Plaque haute Prototype 3.step
260.7 x 100.7 x 5.50 mm

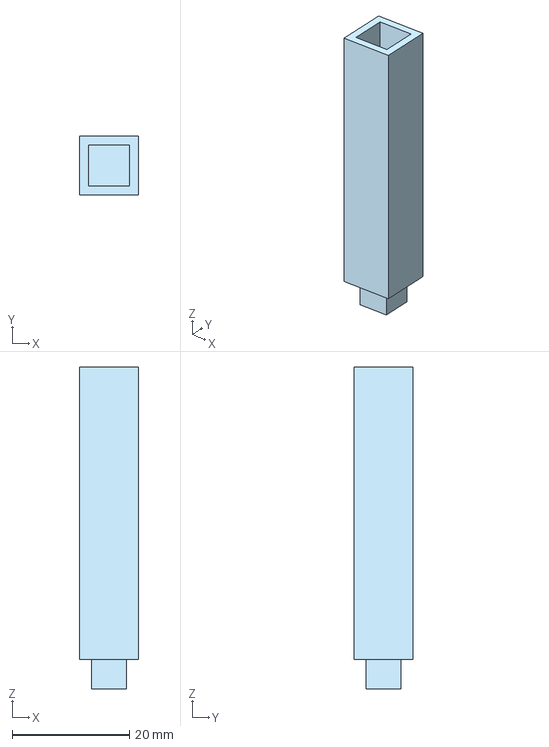
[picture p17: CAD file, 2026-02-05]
Projet G1-G2/Lévitateur à une plaque/Conception Assistée par Ordinateur/Pied Prototype 2.step
10.0 x 10.0 x 55.0 mm

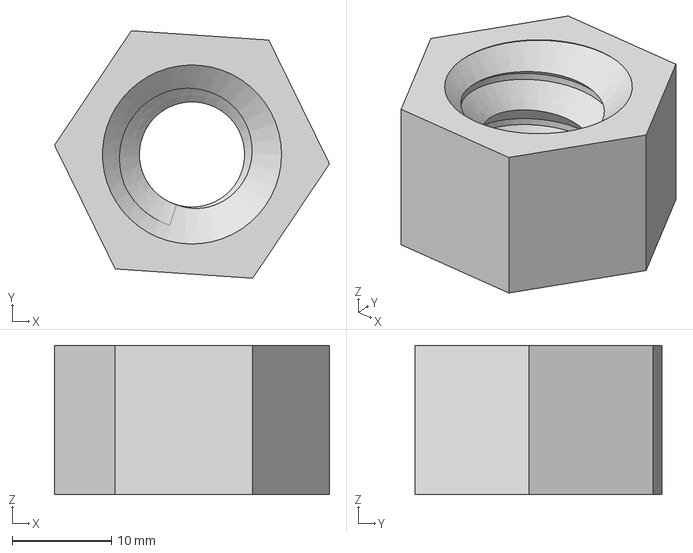
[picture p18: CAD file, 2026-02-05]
Projet G1-G2/Lévitateur à deux plaques/Conception Assistée par Ordinateur/Écrou Prototype 3.step
27.6 x 24.9 x 15.0 mm

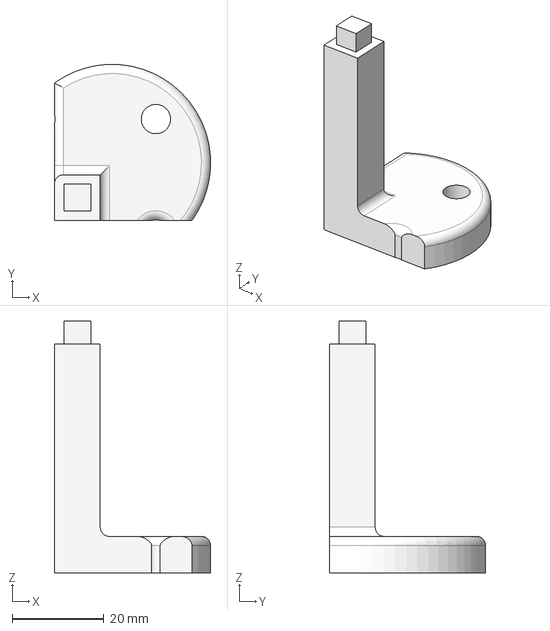
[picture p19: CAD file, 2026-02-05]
Projet G1-G2/Lévitateur à une plaque/Conception Assistée par Ordinateur/Pied (+stable) Prototype 2.step
34.1 x 34.1 x 55.0 mm

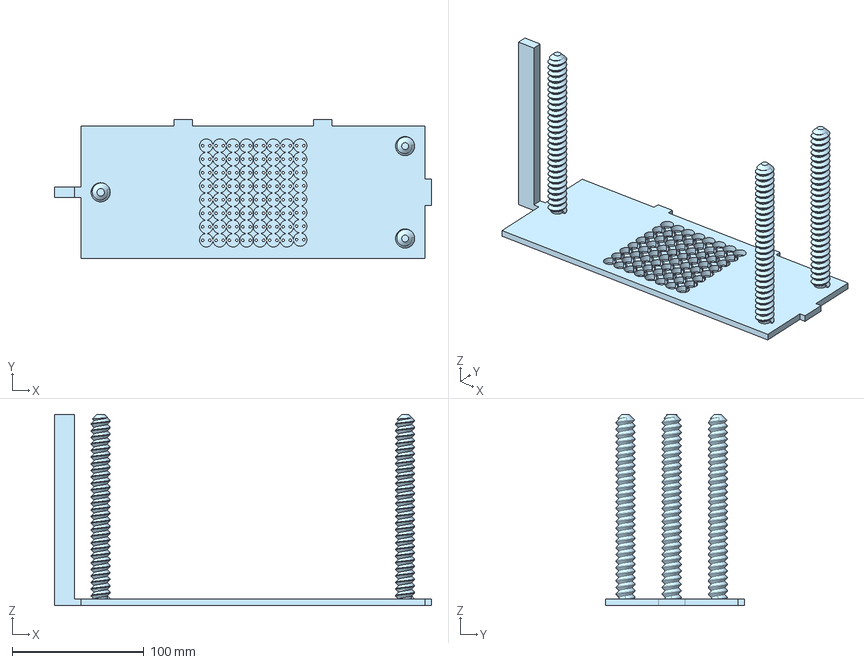
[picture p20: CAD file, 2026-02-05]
Projet G1-G2/Lévitateur à deux plaques/Conception Assistée par Ordinateur/Plaque basse Prototype 3.step
285.7 x 105.7 x 145.0 mm

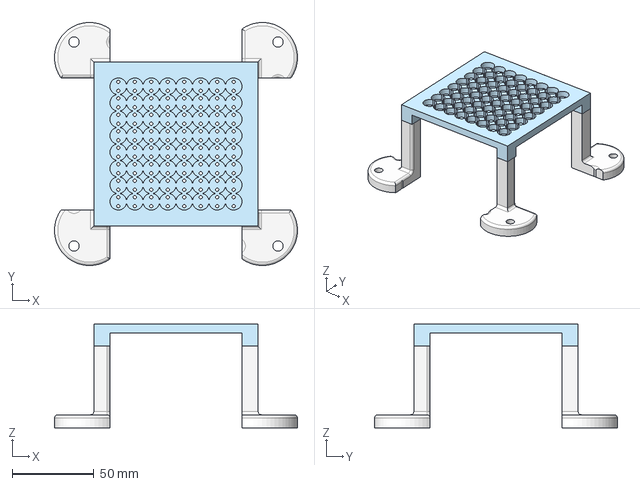
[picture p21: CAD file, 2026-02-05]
Projet G1-G2/Lévitateur à une plaque/Conception Assistée par Ordinateur/Montage Prototype 2.step
148.9 x 148.9 x 63.5 mm

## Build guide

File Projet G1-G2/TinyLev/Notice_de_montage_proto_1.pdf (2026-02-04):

# NOTICE DE MONTAGE DU TINYLEV

## Guide d’assemblage pas à pas

3 février 2026

## Sommaire

1 Matériel et préparation | 2
2 Montage des transducteurs | 3
3 Câblage et électronique | 4
4 Assemblage final et tests | 4

## 1 Matériel et préparation

### 1.1 Étape 1 : Inventaire des composants

Rassemblez tous les composants nécessaires (transducteurs à ultrasons, Arduino Nano, driver de moteur L298N, alimentation, etc.), commandés sur ce site (https://eu.robotshop.com/de/products/acoustic-levitator-kit) (Acoustic Levitator Kit de RoboShop).

Outils nécessaires :
- Imprimante 3D ;
- Fer à souder, étain et flux ;
- Pistolet à colle chaude ;
- Multimètre ;
- Pince à dénuder ;
- Tournevis et pinces ;
- Oscilloscope avec deux sondes.

### 1.2 Étape 2 : Impression 3D

Imprimez en 3D la structure de base (support) qui accueillera les transducteurs, voici le lien STL. (https://content.instructables.com/F78/ZW23/JKN8P8JS/F78ZW23JKN8P8JS.stl)

### 1.3 Étape 3 : Finition du support

Nettoyez la pièce imprimée (limez les bords et les trous) pour que les composants s’insèrent parfaitement. Le rendu final du socle devrait ressembler à la figure 1.

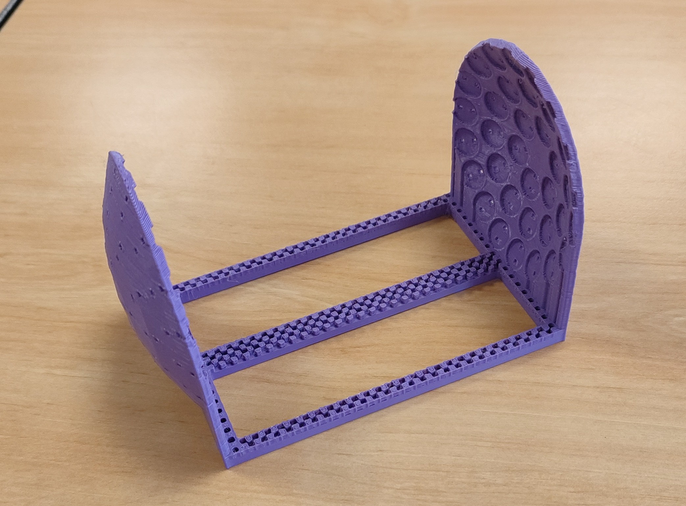
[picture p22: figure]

Figure 1 – Socle TinyLev imprimé en 3D

## 2 Montage des transducteurs

### 2.1 Étape 4 : Polarité

Identifiez la polarité des transducteurs (+/-) ; pour cela voir le paragraphe sur la polarité des transducteurs.

### 2.2 Étape 5 : Fixation

À l’aide du pistolet à colle chaude, collez les transducteurs dans les logements de la base imprimée en veillant à orienter toutes les pattes marquées vers le centre.

### 2.3 Étape 6 : Interconnexion

Reliez les pattes des transducteurs entre elles en enroulant du fil dénudé pour former des anneaux concentriques.

### 2.4 Étape 7 : Soudure

Soudez les connexions faites précédemment afin d’assurer un bon contact électrique.

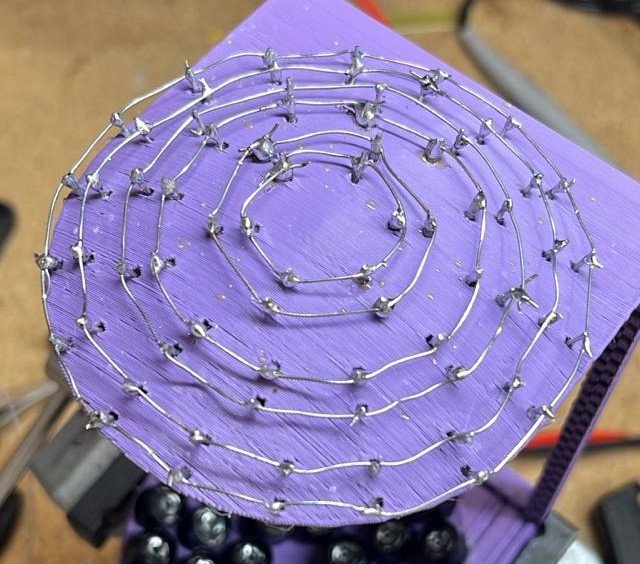
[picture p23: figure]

Figure 2 – Câblage des anneaux concentriques

## 3 Câblage et électronique

### 3.1 Étape 8 : Préparation du câblage

Préparez quatre longs fils (deux rouges, deux noirs) pour relier les rangées de transducteurs au driver.

### 3.2 Étape 9 : Raccordement aux anneaux

Soudez ces longs fils aux anneaux de transducteurs que vous avez créés.

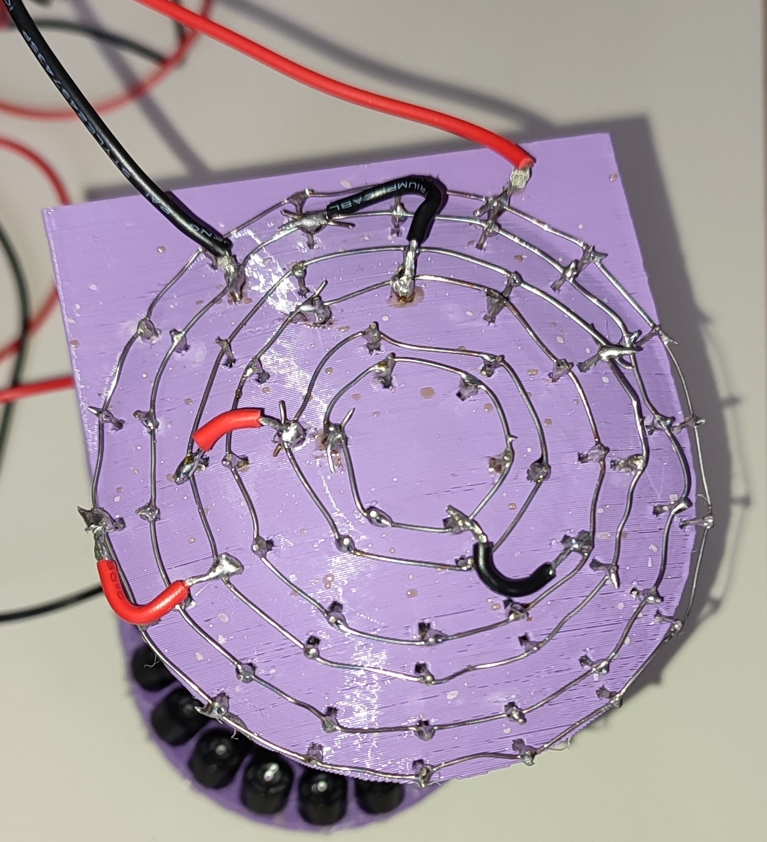
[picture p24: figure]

Figure 3 – Soudure des fils d’alimentation des anneaux

### 3.3 Étape 10 : Préparation de l’Arduino

Soudez les barrettes de connexion (headers) sur l’Arduino Nano.

## 4 Assemblage final et tests

### 4.1 Étape 11 : Alimentation et interrupteur

Préparez le connecteur d’alimentation DC et l’interrupteur en soudant les fils nécessaires.

### 4.2 Étape 12 : Montage final

Collez le connecteur et l’interrupteur, puis effectuez tout le câblage entre l’alimentation, le driver et l’Arduino selon le schéma.

Le câblage entre l’Arduino et le prototype doit être similaire à celui-ci :

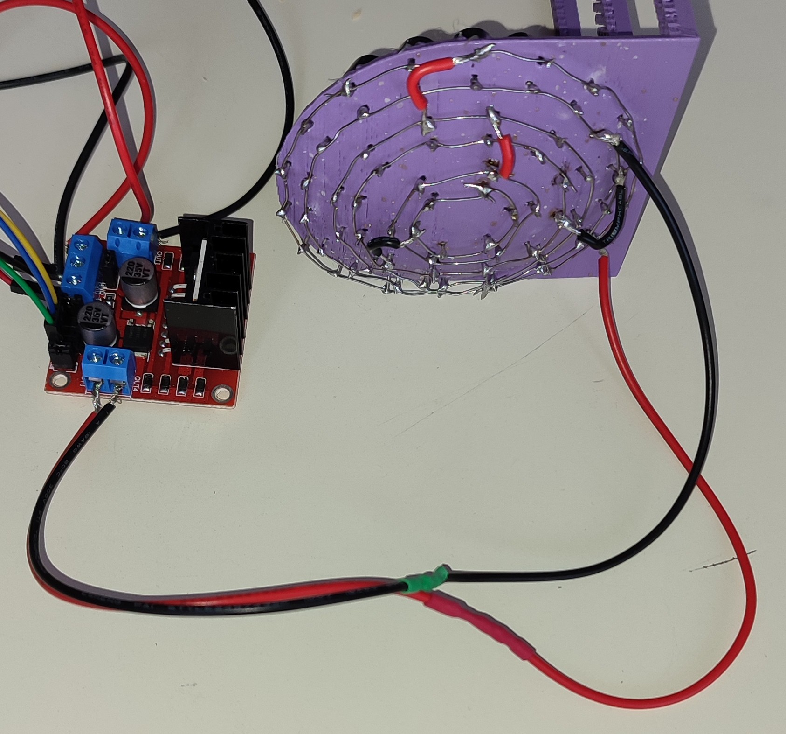
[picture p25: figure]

Figure 4 – Câblage entre l’Arduino Nano et le TinyLev

### 4.3 Étape 13 : Test de signal

Mettez sous tension pour tester le driver et vérifier (si possible avec un oscilloscope) qu’il génère bien un signal carré de 40kHz.

### 4.4 Étape 14 : Vérification électrique

Vérifiez avec un multimètre qu’il n’y a aucun court-circuit entre les fils rouges et noirs.

### 4.5 Étape 15 : Test de fonctionnement

Testez les transducteurs pour vous assurer qu’ils fonctionnent et sont en phase.

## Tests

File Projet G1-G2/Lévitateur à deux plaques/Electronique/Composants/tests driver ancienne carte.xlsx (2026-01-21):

Nb driver | Entrée A | Sortie A | Entrée B | Sortie B | Après changement
1 | ok | ok | ok | ok
2 | ok | ok | ok | ok
3 | ok | ok | ok | ok
4 | ok | ok | ok | ok
5 | ok | ok | ok | ok
6 | ok | ok | ok | ok
7 | ok | ok | ok | ok
8 | ok | ok | ok | ok
9 | ok | ok | ok | ok
10 | ok | ok | ok | ok
11 | ok | ok | ok | ok
12 | ok | ok | ok | ok
13 | ok | ok | ok | ok
14 | NON | NON | ok | ok
15 | ok | ok | ok | ok
16 | ok | ok | ok | ok
17 | NON | NON | NON | NON | tout ok
18 | ok | ok | ok | ok
19 | ok | ok | ok | ok
20 | ok | ok | ok | ok
21 | ok | ok | NON | NON | tout ok
22 | ok | ok | ok | ok
23 | ok | ok | ok | ok
24 | ok | ok | ok | ok
25 | ok | ok | ok | ok
26 | ok | NON | ok | ok | tout ok
27 | ok | ok | ok | ok
28 | ok | NON | ok | ok | tout ok
29 | ok | ok | ok | ok
30 | ok | ok | ok | ok
31 | ok | ok | ok | ok
32 | ok | ok | ok | ok

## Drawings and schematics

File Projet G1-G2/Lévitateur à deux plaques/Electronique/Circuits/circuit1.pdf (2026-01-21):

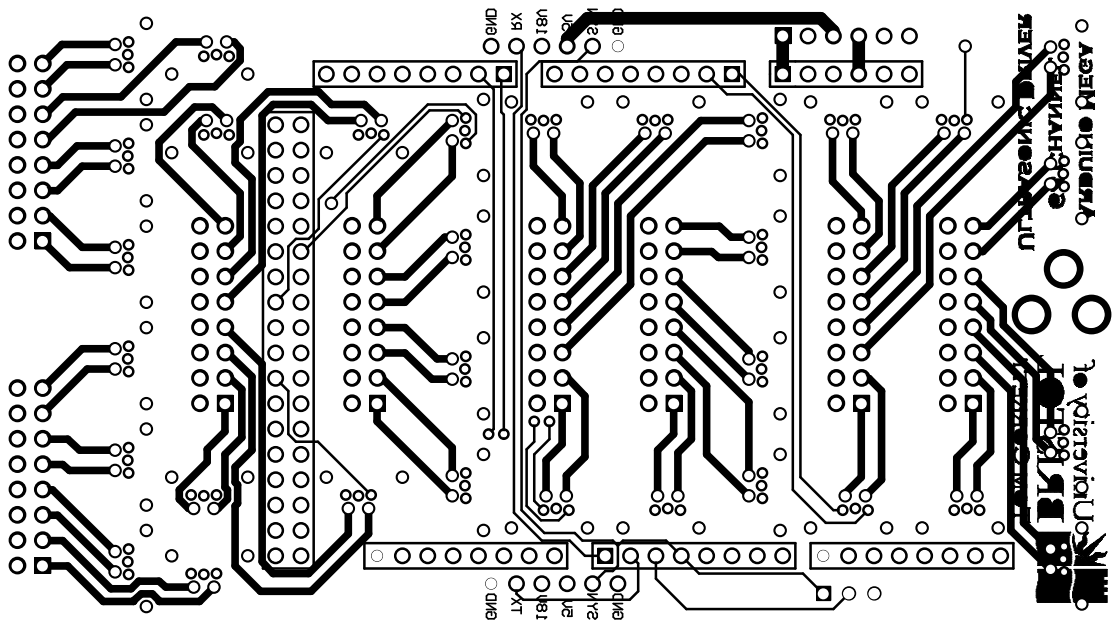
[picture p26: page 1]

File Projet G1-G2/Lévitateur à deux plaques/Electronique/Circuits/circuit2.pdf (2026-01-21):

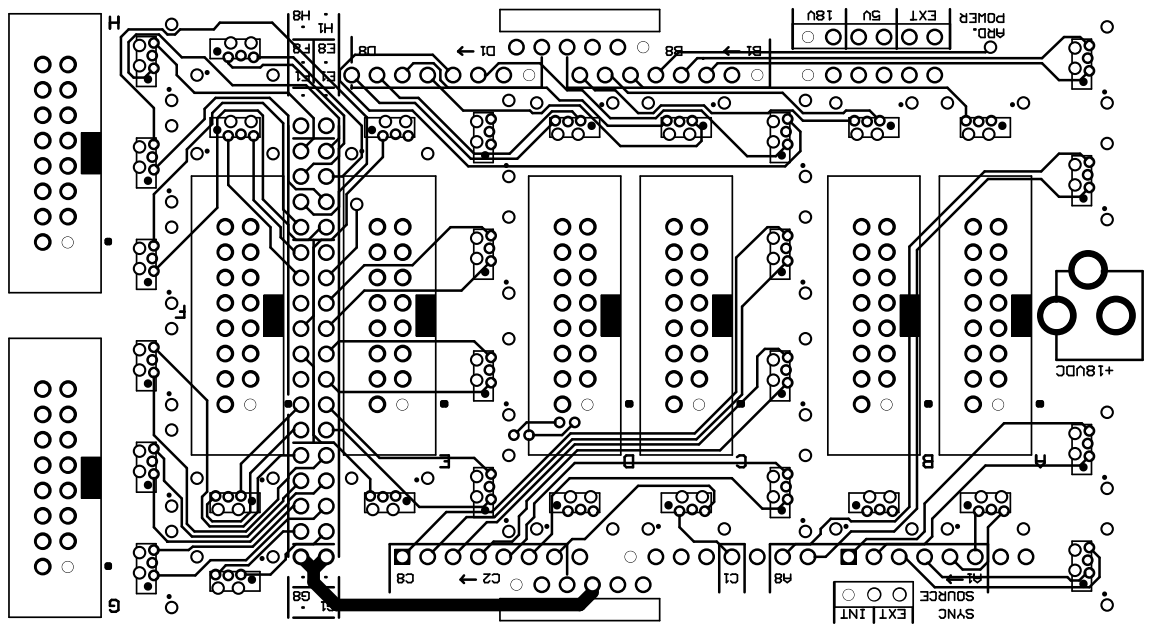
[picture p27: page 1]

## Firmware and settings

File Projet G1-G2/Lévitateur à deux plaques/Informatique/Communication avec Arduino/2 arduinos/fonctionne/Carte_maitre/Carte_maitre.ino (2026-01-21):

#include <avr/sleep.h>
#include <avr/power.h>

#define N_PATTERNS 32
#define N_TRANSDUCTEUR 80
#define N_PORTS 10
#define N_DIVS 10
#define N_T 8

//ports A C L B K F H D G J

#define WAIT() __asm__ __volatile__("nop\n\t""nop\n\t""nop\n\t""nop\n\t""nop\n\t""nop\n\t""nop\n\t""nop\n\t""nop\n\t""nop\n\t")
#define OUTPUT_WAVE(pointer, d)  PORTA = pointer[d*N_PORTS + 0]; PORTC = pointer[d*N_PORTS + 1]; PORTL = pointer[d*N_PORTS + 2]; PORTB = pointer[d*N_PORTS + 3]; PORTK = pointer[d*N_PORTS + 4]; PORTF = pointer[d*N_PORTS + 5]; PORTH = pointer[d*N_PORTS + 6];  PORTD = pointer[d*N_PORTS + 7]; PORTG = pointer[d*N_PORTS + 8]; PORTJ = pointer[d*N_PORTS + 9]

static byte buffer[ N_DIVS * N_PORTS];
volatile uint8_t sync_cnt = 0;  // compteur de fronts sur pin 3 (INT5)

// Attente robuste de N ticks (gère le wrap 0..255 et les ticks manqués)
static inline void wait_ticks(uint8_t n, volatile uint8_t* last_seen) {
  uint8_t start = *last_seen;
  while ( (uint8_t)(sync_cnt - start) < n ) { /* spin, interruptions actives */ }
  *last_seen = sync_cnt;
}

static inline void wait_substep(volatile uint16_t* tref, uint16_t ticks)
{
  uint16_t start = *tref;
  while ((uint16_t)(TCNT4 - start) < ticks) {
    // attente active, base de temps = Timer4
  }
  *tref = start + ticks;
}

void setup()
{
  //set as output ports A C L B K F H D G J
  DDRA = DDRC = DDRL = DDRB = DDRK = DDRF = DDRH = DDRD = DDRG = DDRJ = 0xFF;
  //low signal on all of them
  PORTA = PORTC = PORTL = PORTB = PORTK = PORTF = PORTH = PORTD = PORTG = PORTJ = 0x00;

  //clear the buffers
  for (int i = 0; i < (N_PATTERNS * N_DIVS * N_PORTS); ++i) {
    buffer[i] = 0;
  }
  
  // INT5 (PE5 = pin 3 sur Mega) sur FRONT DESCENDANT
  EICRB |= (1 << ISC51);   // ISC51:50 = 10 => front descendant
  EICRB &= ~(1 << ISC50);
  EIFR   = (1 << INTF5);   // clear tout pending
  EIMSK |= (1 << INT5);    // enable INT5

  // generate a sync signal of 40khz in pin 2
  pinMode (2, OUTPUT);
  noInterrupts();           // disable all interrupts
  TCCR3A = bit (WGM10) | bit (WGM11) | bit (COM1B1); // fast PWM, clear OC1B on compare
  TCCR3B = bit (WGM12) | bit (WGM13) | bit (CS10);   // fast PWM, no prescaler
  OCR3A =  (F_CPU / 80000L) - 1; //should only be -1 but fine tunning with the scope determined that -5 gave 40kHz almost exactly
  OCR3B = (F_CPU / 80000L) / 2;
  TCCR4A=0;
  TCCR4B=(1<<CS40);
  TCNT4=0;

  interrupts();             // enable all interrupts

  //sync in signal at pin 3
  pinMode(3, INPUT_PULLUP); //please connect pin3 to pin 2


  // disable everything that we do not need
  ADCSRA = 0;  // ADC
  power_adc_disable ();
  power_spi_disable();
  power_twi_disable();
  power_timer0_disable();
  power_usart1_disable();
  power_usart2_disable();
  power_usart3_disable();
  //power_usart0_disable();
  

//creation d'une liste (de liste des valeur binaire) que chaque transducteur doit prendre 64*10
  byte buffer[N_DIVS * N_PORTS] = {
  0xFF, 0xFF, 0xFF, 0xFF, 0xFF, 0xFF, 0x7B, 0x8F, 0x07, 0x03,
  0xFF, 0xFF, 0xFF, 0xFF, 0xFF, 0xFF, 0x7B, 0x8F, 0x07, 0x03,
  0xFF, 0xFF, 0xFF, 0xFF, 0xFF, 0xFF, 0x7B, 0x8F, 0x07, 0x03,
  0xFF, 0xFF, 0xFF, 0xFF, 0xFF, 0xFF, 0x7B, 0x8F, 0x07, 0x03,
  0x42, 0x32, 0xCB, 0x4D, 0x5A, 0xBD, 0x10, 0x82, 0x00, 0x01,
  0x00, 0x00, 0x00, 0x00, 0x00, 0x00, 0x00, 0x00, 0x00, 0x00,
  0x00, 0x00, 0x00, 0x00, 0x00, 0x00, 0x00, 0x00, 0x00, 0x00,
  0x00, 0x00, 0x00, 0x00, 0x00, 0x00, 0x00, 0x00, 0x00, 0x00,
  0x00, 0x00, 0x00, 0x00, 0x00, 0x00, 0x00, 0x00, 0x00, 0x00,
  0xBD, 0xCD, 0x34, 0xB2, 0xA5, 0x42, 0x6B, 0x0D, 0x07, 0x02
};


//initialisation des variables
  byte* emittingPointerH = & buffer[0]; 
  byte* emittingPointerL = & buffer[N_PORTS * N_DIVS / 2];
  
  Serial.begin(115200);
  while(!Serial.available());
  //Serial.read();
  Serial.write(0x55);


//------boucle------------------------

LOOP:
{
  uint8_t last = sync_cnt;   // point de départ calé sur l’horloge externe

  // Exemple : 1 front (= 25 µs si 40 kHz) entre chaque OUTPUT_WAVE
  wait_ticks(1,&last);
  OUTPUT_WAVE(emittingPointerH, 0); WAIT();
  OUTPUT_WAVE(emittingPointerH, 1); WAIT();
  OUTPUT_WAVE(emittingPointerH, 2); WAIT();
  OUTPUT_WAVE(emittingPointerH, 3); WAIT();
  OUTPUT_WAVE(emittingPointerH, 4); WAIT();
  OUTPUT_WAVE(emittingPointerL, 0); WAIT();
  OUTPUT_WAVE(emittingPointerL, 1); WAIT();
  OUTPUT_WAVE(emittingPointerL, 2); WAIT();
  OUTPUT_WAVE(emittingPointerL, 3); WAIT();
  OUTPUT_WAVE(emittingPointerL, 4); WAIT();


  goto LOOP;
}
}

void loop() {}

ISR(INT5_vect) {
  sync_cnt++;  // 1 tick = 1 front reçu depuis le maître
}

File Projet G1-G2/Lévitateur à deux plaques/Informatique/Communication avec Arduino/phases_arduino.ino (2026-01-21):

/* To compile this file correctly you will need to:

*** add the following inline functions in the public interface (after "public:") of Program Files (x86)\Arduino\hardware\arduino\avr\cores\arduino\HardwareSerial.h
inline bool _dataAvailable() {return _rx_buffer_head != _rx_buffer_tail; }
inline byte _peekData() { return _rx_buffer[_rx_buffer_tail]; }
inline void _discardByte() { _rx_buffer_tail = (rx_buffer_index_t)(_rx_buffer_tail + 1) % SERIAL_RX_BUFFER_SIZE; }

*** If you are using an IDE >1.6.X you will need to compile with -O3 (optimization speed), in some cases this does not work and you are forced to compile with 1.6. The binaries are also avaialable.
*** Comment the line power_usart3_disable(); if it gives you an error.

*/

#include <avr/sleep.h>
#include <avr/power.h>

#define N_PATTERNS 32
#define N_TRANSDUCTEUR 80
#define N_PORTS 10
#define N_DIVS 10
#define N_T 8

//ports A C L B K F H D G J

#define WAIT(a) __asm__ __volatile__ ("nop")
#define OUTPUT_WAVE(pointer, d)  PORTA = pointer[d*N_PORTS + 0]; PORTC = pointer[d*N_PORTS + 1]; PORTL = pointer[d*N_PORTS + 2]; PORTB = pointer[d*N_PORTS + 3]; PORTK = pointer[d*N_PORTS + 4]; PORTF = pointer[d*N_PORTS + 5]; PORTH = pointer[d*N_PORTS + 6];  PORTD = pointer[d*N_PORTS + 7]; PORTG = pointer[d*N_PORTS + 8]; PORTJ = pointer[d*N_PORTS + 9]

static byte buffer[ N_DIVS * N_PORTS];

void setup()
{
  //set as output ports A C L B K F H D G J
  DDRA = DDRC = DDRL = DDRB = DDRK = DDRF = DDRH = DDRD = DDRG = DDRJ = 0xFF;
  //low signal on all of them
  PORTA = PORTC = PORTL = PORTB = PORTK = PORTF = PORTH = PORTD = PORTG = PORTJ = 0x00;

  //clear the buffers
  for (int i = 0; i < (N_PATTERNS * N_DIVS * N_PORTS); ++i) {
    buffer[i] = 0;
  }

//initial pattern ==> sinus avec toute les sorties qui sont en phases
  for (int i = 0; i < (N_PORTS*N_DIVS/2); ++i){
     buffer[i] = 0xFF;
  }
  
  
  // generate a sync signal of 40khz in pin 2
  pinMode (2, OUTPUT);
  noInterrupts();           // disable all interrupts
  TCCR3A = bit (WGM10) | bit (WGM11) | bit (COM1B1); // fast PWM, clear OC1B on compare
  TCCR3B = bit (WGM12) | bit (WGM13) | bit (CS10);   // fast PWM, no prescaler
  OCR3A =  (F_CPU / 40000L) - 5; //should only be -1 but fine tunning with the scope determined that -5 gave 40kHz almost exactly
  OCR3B = (F_CPU / 40000L) / 2;
  interrupts();             // enable all interrupts

  //sync in signal at pin 3
  pinMode(3, INPUT_PULLUP); //please connect pin3 to pin 2


  // disable everything that we do not need
  ADCSRA = 0;  // ADC
  power_adc_disable ();
  power_spi_disable();
  power_twi_disable();
  power_timer0_disable();
  power_usart1_disable();
  power_usart2_disable();
  power_usart3_disable();
  //power_usart0_disable();

  Serial.begin(115200);

//--------ecriture-du-buffer---------------------------

  static float Phi=[N_TRANSDUCTEUR];
  for (int i=0;i<N_TRANSDUCTEUR;i++){
    Phi[i]=0;
  }

//creation d'une liste (de liste des valeur binaire) que chaque transducteur doit prendre 64*10

  int oct_T[N_TRANSDUCTEUR][N_DIVS];
  for (int i=0; i<N_TRANSDUCTEUR, i++){
    for (int j=0;j<N_DIVS;j++){
      int v = 0;
      float angle = 2*PI*j/N_DIVS + Phi[i];
      float value = sin (angle);
      if (value<0){oct_T[i][j]=0}
      else{oct_T[i][j]=1}
    }
  }
  int oct_P[N_DIVS][N_PORTS][N_TRANSDUCTEUR/N_PORTS]
  for (int j=0;j<N_DIVS;j++){
    for (int i=0; i<N_PORTS, i++){
      for (int k=0; k<N_T ; k++){
        oct_P[j][i].append(oct_T[i*N_T+k][j]);
      }
    }
  }
  for (int i=0;i<N_DIVS;i++){
    for (int j=0;j<N_PORTS;j++){
      byte value =0;
      for (int k=0;k<8;k++){
        value = (value << 1) | (oct_P[i][j][k] & 1);
      }
      buffer[i*N_DIVS+j]=value;
    }
  }
  


//initialisation des variables
  bool byteReady = false;

  bool emittingA = true;
  byte* emittingPointerH = & buffer[0]; //code les instant O à T/2 (chaqu'un contient donc 5 instants)
  byte* emittingPointerL = & buffer[N_PORTS * N_DIVS / 2]; //code les instant T/2 à T


//------boucle------------------------

LOOP:
  while (PINE & 0b00100000); //wait for pin 3 (E5 Sync In) to go low

  OUTPUT_WAVE(emittingPointerH, 0); byteReady = Serial._dataAvailable(); 
  OUTPUT_WAVE(emittingPointerH, 1); bReceived = Serial._peekData(); 
  OUTPUT_WAVE(emittingPointerH, 2);
  OUTPUT_WAVE(emittingPointerH, 3); 
  OUTPUT_WAVE(emittingPointerH, 4); 
  OUTPUT_WAVE(emittingPointerL, 0);
  OUTPUT_WAVE(emittingPointerL, 1);
  OUTPUT_WAVE(emittingPointerL, 2);
  OUTPUT_WAVE(emittingPointerL, 3);
  OUTPUT_WAVE(emittingPointerL, 4); 
  
  goto LOOP;

}

void loop() {}

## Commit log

2026-02-04 Update and rename DriverMEGA.ino to DriverMEGA.ino
2026-02-04 Rename Projet G1-G2/Lévitateur à deux plaques/Informatique/Carte_esclave.ino to Projet G1-G2/Lévitateur à deux plaques/Informatique/Communication 2 Arduino/Carte_esclave.ino
2026-02-04 Rename affichage champ de pression.ipynb to Affichage_Champ_De_Pression.ipynb
